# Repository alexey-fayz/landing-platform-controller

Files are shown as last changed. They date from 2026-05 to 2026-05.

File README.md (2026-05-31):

# Active Stabilization Platform Firmware

## Overview

This project implements an embedded firmware for an active stabilization platform that compensates for marine vessel motion (roll and pitch), enabling a quadcopter to land safely on a moving boat or buoy.

The system uses a gimbal-like structure with two BLDC servos, a cascade PID controller, absolute encoder feedback, Hall sensors for commutation, current monitoring, and CAN/UART communication.  
FreeRTOS is used for real-time task management.

---

## Table of Contents

- Features  
- Prerequisites   
- Architecture  
- Communication Interfaces  
- Safety & Monitoring  

---

## Features

- **Two-axis stabilization (roll & pitch)**  
  Keeps the landing platform level despite vessel motion.

- **6-step BLDC commutation**  
  Hall sensors provide rotor position for efficient motor control.

- **Absolute encoder feedback**  
  AS5311 (12-bit, SSI interface) provides precise angular position.

- **Cascade PID control**  
  Inner speed loop + outer position loop for smooth and accurate control.

- **Current limiting & monitoring**  
  INA219 (I²C) provides over-current protection and adaptive power reduction.

- **Real-time operating system (FreeRTOS)**  
  Dedicated tasks for control, communication, telemetry, and diagnostics.

- **CAN bus communication (250 kbit/s)**  
  Receives target angles and transmits telemetry data.

- **UART debug console (115200 baud)**  
  Simple command interface for manual control and debugging.

- **Modular architecture**  
  Clear separation of BSP, control, communication, and utilities.

---

## Prerequisites

### Hardware

- STM32L451CET6 microcontroller  
- BLDC motors with Hall sensors  
- DRV8353 gate driver  
- AS5311 absolute encoder  
- INA219 current sensor  
- CAN transceiver (e.g., ISO1050)  
- 24 V / 5 V / 3.3 V power supplies  

### Software

- STM32CubeMX (project generation)  
- STM32CubeIDE / Keil / IAR / ARM GCC toolchain  
- FreeRTOS (included via CubeMX)  
- UART terminal / CAN analyzer (optional)  

---

## Architecture

The firmware is organized into logical layers:

- **App/** – system initialization, global state, interrupt callbacks
- **BSP/** – low-level hardware drivers (encoder, Hall sensors, DRV8353, INA219)
- **Control/** – PID controllers, filters, estimators, trajectory generation
- **Communication/** – CAN protocol, UART telemetry, command parser

All hardware-specific code is isolated in BSP, ensuring that control logic remains portable and testable.

---

## Communication Interfaces

### UART Console (115200 baud, 8N1)

Connection:
- PA2 → TX  
- PA3 → RX  

#### Commands

| Command | Action |
|---|---|
| `enable` | Enable motor control |
| `disable` | Disable motor control |
| `angle 12.3` | Set target angle (degrees) |
| `status` | Show system state |

---

### CAN Bus (250 kbit/s, standard ID)

#### Receive (ID: 0x100)

Target angle command:

- Data length: 2 bytes  
- Format:
  - `angle (deg) = (byte0 << 8 | byte1) / 10.0`

---

#### Transmit (ID: 0x101)

Telemetry frame (6 bytes):

- `uint16` current angle ×10  
- `int16` current speed ×10  
- `uint8` enable flag  
- `uint8` error flags  

This protocol is compatible with marine-style CAN networks (similar to NMEA2000-like systems).

---

## Safety & Monitoring

### Over-current protection
The INA219 sensor continuously measures motor current.  
If the current exceeds a defined threshold:
- Motor power is reduced gradually, or
- The system is shut down if the condition persists

---

### Fault detection
The DRV8353 gate driver provides an `nFAULT` signal.  
On fault detection:
- PWM outputs are disabled immediately
- System enters safe state

---

### FreeRTOS safety mechanisms
The system uses built-in RTOS safety features:
- Stack overflow detection hooks
- Runtime error callbacks
- Task watchdog logic (if enabled)

---

### Emergency stop behavior
The system can be disabled via:
- UART `disable` command
- CAN stop command

In all cases:
- Motor outputs are immediately disabled
- Control loops are paused
- System transitions to safe idle state

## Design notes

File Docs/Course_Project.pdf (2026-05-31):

Министерство науки и высшего образования Российской Федерации
Федеральное государственное автономное образовательное учреждение
высшего образования
«Московский государственный технический университет имени Н.Э. Баумана
(национальный исследовательский университет)» (МГТУ им. Н.Э. Баумана)

ФАКУЛЬТЕТ СПЕЦИАЛЬНОЕ МАШИНОСТРОЕНИЕ
КАФЕДРА РОБОТОТЕХНИЧЕСКИЕ СИСТЕМЫ И МЕХАТРОНИКА

## РАСЧЕТНО-ПОЯСНИТЕЛЬНАЯ ЗАПИСКА

## К КУРСОВОМУ ПРОЕКТУ НА ТЕМУ:

## Разработка мехатронной системы стабилизации платформы

Студент | СМ7-71Б | Файздрахманов А.И.
(группа) | (подпись, дата) | (И.О. Фамилия)
Руководитель
курсового проекта | Синицын А.В.
(подпись, дата) | (И.О. Фамилия)

2025 г.

Министерство науки и высшего образования Российской Федерации Федеральное государственное автономное образовательное учреждение высшего образования
«Московский государственный технический университет имени Н.Э. Баумана (национальный исследовательский университет)» (МГТУ им. Н.Э. Баумана)
УТВЕРЖДАЮ

Заведующий кафедрой
(индекс)

(И.О. Фамилия)
(подпись)
(дата)
ЗАДАНИЕ
на выполнение курсового проекта

по дисциплине Электронные устройства СРТС ч.2
Студент группы Файздрахманов Алексей Игоревич СМ7-71Б
| (Фамилия, имя, отчество)
Тема курсового проекта Разработка мехатронной системы стабилизации платформы

Направленность КП (учебная, исследовательская, практическая, производственная, др.) учебная

Источник тематики (кафедра,

предприятие, НИР) | кафедра
Задание Проанализировать техническое задание, разработать функциональную и структурную схемы системы управления приводом, разработать плату управления двигателем приводов на оси дифферента и оси крена, спроектировать печатную плату, разработать конструкторскую документацию, состоящую из принципиальной электрической схемы, сборочного чертежа, чертежа печатной платы, спецификации и перечня элементов.

Оформление курсового проекта:
Расчетно-пояснительная записка на 48 листах формата А4.
Перечень графического (иллюстративного) материала (чертежи, плакаты, слайды и т.п.) Схема электрическая принципиальная А3, чертёж печатной платы А3, сборочный чертёж А3, перечень элементов 3 листа А4, спецификация к сборочному чертежу 3 листа А4.

Дата выдачи задания « ___ » ____________ 20__ г.
Руководитель курсового проекта | А.В.Синицын
(подпись, дата) | (И.О. Фамилия)
Студент | А.И.Файздрахманов
(подпись, дата) | (И.О. Фамилия)
Примечание: Задание оформляется в двух экземплярах: один выдается студенту, второй хранится на кафедре.

Министерство науки и высшего образования Российской Федерации Федеральное государственное автономное образовательное учреждение высшего образования
«Московский государственный технический университет имени Н.Э. Баумана (национальный исследовательский университет)» (МГТУ им. Н.Э. Баумана)

КАЛЕНДАРНЫЙ ПЛАН
на выполнение курсового проекта
по дисциплине
Студент группы
(Фамилия, имя, отчество)
Тема курсового
проекта
№ п/п | Наименование этапов выпускной квалификационной работы | Сроки выполнения этапов | Отметка о выполнении
план | факт | Руководитель КП | Куратор
1. Задание на выполнение курсового | проекта
2. | 1 модуль | ____________ Планируемая дата
3. | 2 модуль | ____________ Планируемая дата
4. | Оформление РПЗ | ____________ Планируемая дата
5. Подготовка доклада и презентации | (при необходимости) | ____________ Планируемая дата
6. | Защита курсового проекта | ____________ Планируемая дата
Студент ________________________ | Руководитель проекта _________________________ (подпись, дата) | (подпись, дата)

Оглавление

Введение
Современные робототехнические и мехатронные системы предъявляют всё более высокие требования к качеству, точности и надёжности управления электроприводами. Особенно это касается мобильных и динамически неустойчивых платформ, в составе которых используется сложная система приводов и сенсоров, таких как стабилизирующиеся платформы, манипуляторы, дроны и системы посадки беспилотных летательных аппаратов. В таких комплексах электрический привод является не просто исполнительным механизмом, а элементом, определяющим общую динамику системы, её энергоэффективность и устойчивость при внешних возмущениях.
В последние годы широкое распространение получили бесколлекторные двигатели постоянного тока (BLDC), обладающие высокой удельной мощностью, высоким КПД, малым уровнем шума и отсутствием изнашиваемых коллекторных узлов. Благодаря электронной коммутации обмоток BLDC-двигатели обеспечивают плавное управление моментом и скоростью вращения. Эти преимущества делают их особенно востребованными в малогабаритных робототехнических системах, в том числе и в составе активных выравнивающихся платформ, используемых для автономной посадки дронов на подвижные объекты, например, морские суда или плавучие базы.
В данной курсовом проекте по дисциплине «Электронные устройства» рассматривается проектирование и разработка управляющей платы для бесколлекторного двигателя, предназначенного для работы в составе активной двухосевой стабилизирующей платформы.

Данная плата является частью системы управления, обеспечивающей движение по двум угловым степеням свободы — по крену и по дифференту. Основными функциями платы являются формирование управляющих сигналов для силового драйвера, измерение токов и напряжений в системе, обработка сигналов от датчиков положения ротора, а также обеспечение интерфейса обмена данными с управляющим микроконтроллером.
Таким образом, в ходе выполнения курсового проекта будет спроектировано электронное устройство — управляющая плата для бесколлекторного двигателя, обеспечивающая реализацию базовых функций управления и защиты. В процессе работы будут рассмотрены схемные решения силовой и измерительной части, структура управления, выбор элементной базы, а также особенности компоновки печатной платы. Полученные результаты станут основой для дальнейшей интеграции платы в общую систему управления стабилизирующейся платформой, разрабатываемой в рамках дипломного проекта.

Управление приводами
В данном проекте было решено управлять обоими приводами с помощью двух разных плат управления. Поскольку блок управления будет находиться рядом с управляемым приводом, сигналы будут передаваться на короткие расстояния, что существенно снижает влияние помех, действующих на линии связи.

Структурная схема усилителя следящего привода

Общая структурная схема усилителя мощности следящего привода изображена на Рис. 1. Она управляется драйвером, управляемым микроконтроллером.

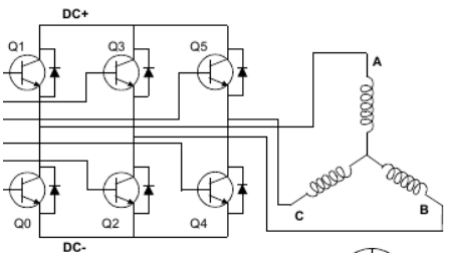
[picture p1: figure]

Рис. 1. Общая схема усилителя мощности следящего привода

Выбор способа управления ДПТ

Существуют два основных способа управления ДПТ: непрерывный и импульсный. При непрерывном способе система обладает сравнительно низким КПД, а транзисторные УМ вносят дополнительную статическую погрешность, поскольку они выполнены по схемам усилителя постоянного тока.

В отличие от непрерывного, импульсный способ управления не обладает этими недостатками и широко используется для управления ДПТ малой и средней мощности. В этом случае ключи работают в режиме класса D и характеризуются меньшими тепловыми потерями. Для данного двигателя будет реализован трапецеидальный способ управления.

Описание трапецеидального способа управления ДПТ

При импульсном управлении по такому способу на ДПТ подается последовательность импульсов одной полярности. Амплитуда соответствует номинальному напряжению якоря UЯН.

# kk = ttuu

TT , | (1)

где k – коэффициент заполнения; tu – длительность импульсов; Т – период следования импульсов.
Коэффициент заполнения пропорционален непрерывному сигналу управления. Если принять Т < TЭ , то скорость двигателя не будет успевать существенно меняться. Значение скорости будет близко к значению, определяемому отношением:
UЯ.СР = k∙UЯН | (2)
Чтобы обеспечить непрерывность тока якоря, а также минимальные потери мощности, следует применить мостовую схему выходного каскада. Такой подход позволяет осуществить режим динамического торможения двигателя между управляющими импульсами. Недостатком мостовой схемы является возможность короткого замыкания.
При этом на фазы двигателя требуется подавать напряжение согласно закону, описанному в таблице 1 и Рис. 2. Здесь sensors – значения с датчиков Холла на роторе двигателя, отражающие его положение.

Таблица 1 – Закон подаваемых сигналов при положительном
| направлении вращения

Электрический угол, ° | Показания датчика Холла | Напряжение на фазах
А | B | C | A | B | C
0-60 | 1 | 0 | 0 | Высокое | - | Низкое
60-120 | 1 | 0 | 1 | Высокое | Низкое | -
120-180 | 0 | 0 | 1 | - | Низкое | Высокое
180-240 | 0 | 1 | 1 | Низкое | - | Высокое
240-300 | 0 | 1 | 0 | Низкое | Высокое | -
300-360 | 1 | 1 | 0 | - | Высокое | Низкое

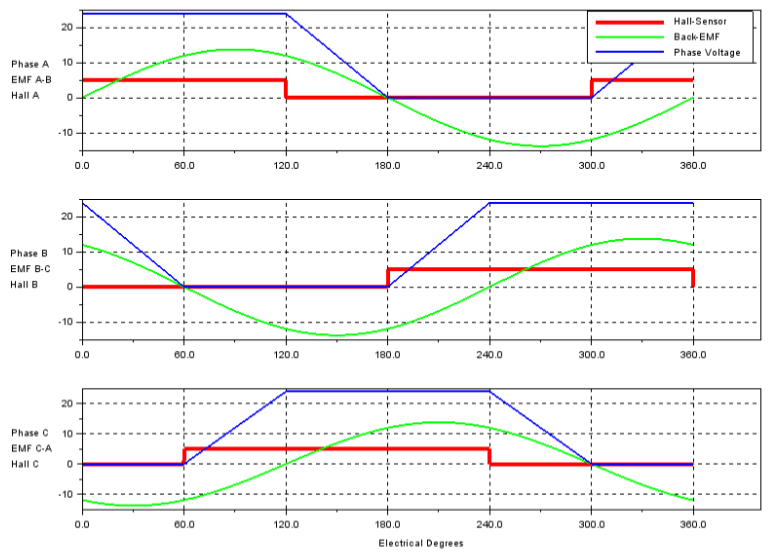
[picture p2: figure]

Рис. 2. Фазные напряжения, показания датчиков и противо-ЭДС на различных обмотках

### 1. Проектирование платы управления на оси

дифферента

### 1.1. Анализ технического задания

В качестве двигателя для данного привода используется трёхфазный бесколлекторный ДПТ с датчиком Холла от компании Fulling Motors FL36RBLS57-24V-4524A. Его характеристики представлены в табл. 2.

Таблица 2 – параметры двигателя FL36RBLS57-24V-4524A
Диаметр | DDд = 36 мм
Мощность | PPд = 24 Вт
Номинальное напряжение | UUд = 24 В
Номинальная скорость | ωωд = 4500 об/мин
Номинальный момент | MMд_ном = 0,05093 Н ∙ м
Сопротивление обмотки | RRд = 2 Ом
Инерция ротора | JJд = 24 ∙ 10⁻⁷ кг ∙ м²
Номинальный ток цепи якоря | IIд = 1,6 А
Пусковой момент | MMд_пуск = 150 Н ∙ мм = 0,15 Н ∙ м
Пусковой ток | IIпуск = 3,8 А

Техническое задание:
Разработать плату управления данным двигателем. Питание платы обеспечить источником питания на 24 В и мощностью 24 Вт.
В ходе конструкторской части работы необходимо:
1) проанализировать техническое задание и подобрать базу необходимых элементов;
2) спроектировать печатную плату в программном пакете Altium Designer;

### 1.2. Разработка структурной схемы

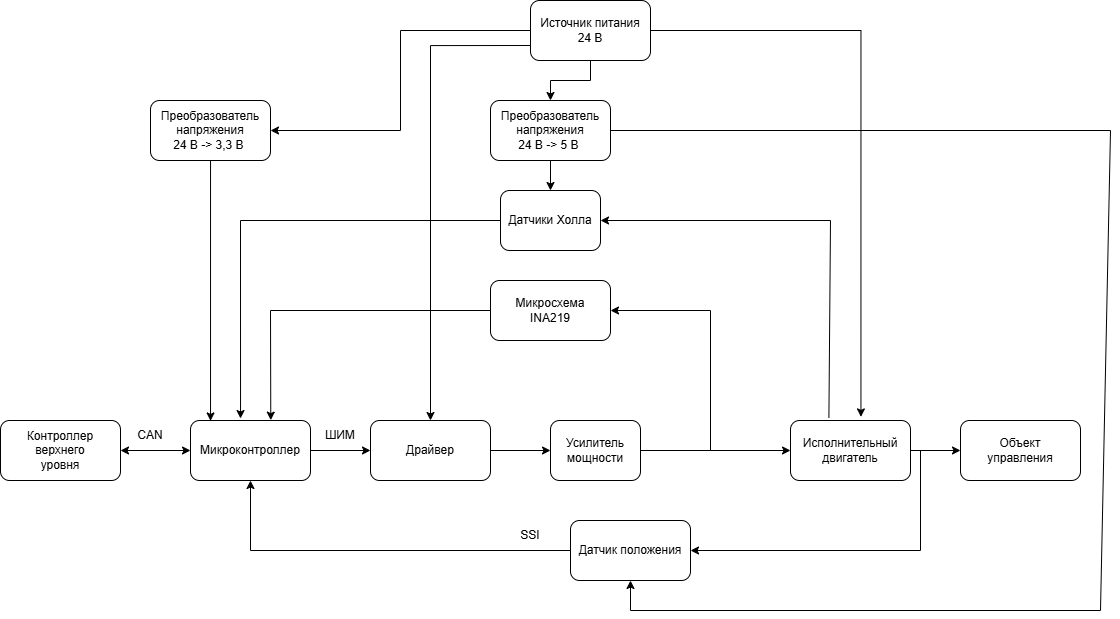
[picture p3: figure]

Рис. 3. Структурная схема системы управления приводом

В данной работе будем выбирать следующие компоненты данной схемы:
- Усилитель мощности (УМ)
- Драйвер

- Датчик положения
- Микроконтроллер
- Преобразователи напряжения

### 1.3. Расчет усилителя мощности

Рассмотрим блок усилителя мощности (рисунок 1). Усилитель мощности будет реализован с использованием мостового каскада. В состав мостового каскада входят полевые транзисторы n-типа с одним источником питания. Все транзисторы были выбраны n-типа для лучшего совпадения их характеристик.
При расчете выходного каскада УМ следует учитывать влияние противо-ЭДС.
1) При разгоне ДПТ в момент времени t=0 : E=0, IЯ = IПУСК. С течением времени IЯ=IНОМ за счет E > 0.
2) При резком изменении направления вращения ротора значение E → UП суммируется с напряжением питания UП, в результате чего в начальный момент времени реверса

# IIЯ = 2IIПУСК (3)

Такое высокое значение тока якоря может вывести из строя ДПТ или транзисторные силовые ключи.
Для того, чтобы исключить влияние выходного каскада УМ как нагрузки, необходимо, чтобы сопротивление ключей моста во включенном состоянии было намного меньше сопротивление якоря двигателя RЯ.

### 1.4. Выбор силовых транзисторных ключей

Выбор силовых транзисторов VT1-VT6 будет проводиться с учетом требований:
1) Напряжение UСИ.MAX = 2*UЯ = 2*24 = 48 В (коэффициент запаса 2)

# 2) IIПУСК = 3,8А, 2 ∗ IIПУСК = 7,6 А

IC.MAX = kЗАПАСА∙ Iогран = 1,2∙7,6 = 9,12 А | (4)

# 3) RRСИ ≤ RRя

20 = 2

| | | 20 = 0.1 Ом | | (5)
4) Частота коммутации должна удовлетворять условия

ff > 10

# TTЭ

= 10

# 0,00072 = 13 889 кГц (6)

для обеспечения непрерывности тока якоря. Примем:

# ff = 15 кГц (7)

В соответствии с этими требованиями выбираем МОП транзистор с
изолированным | затвором | и | каналом | n-типа | фирмы
Youtai Semiconductor IRFR024NTR.
Параметры IRFR024NTR (таблица 3):
Таблица 3 Параметры IRFR024NTR
Параметр | Обозначение | Значение
Максимальное напряжение сток-исток | UСИ.MAX | 55 В
Максимальное напряжение затвор-исток | UЗИ.MAX | 20 В
Максимальный постоянный ток | IС.MAX | 17 А
Сопротивление сток-исток | RСИ | 0,075 Ом
Время нарастания | tн | 34 нс
Время падения | tп | 27 нс
Время задержки включения | tз(вкл) | 4.9 нс
Время задержки выключения | tз(выкл) | 19 нс
tВКЛ=tз(вкл)+tн=4.9 + 34 = 38,9 нс | (8)
tз(вкл) – время задержки при включении, tн – время нарастания
tВЫКЛ=tз(выкл)+tп=19 + 27 = 46 нс | (9)
tз(вкл) – время задержки при выключении, tп – время падения

Временные параметры приведены для UСИ=28 В, UЗИ=10 В, RЗ=24 Ом, IС=10 А.
Напряжение затвор-исток выберем UЗИ = 10 В

Расчет тока управления транзистора

Затвор транзистора представляет собой емкость, которую необходимо зарядить для открытия. Рассчитываем ток управления транзистором:

# IIЗ = QQЗ

# ttнарастания

(10)
Зависимость заряд затвора от напряжений затвор-исток и сток-исток определяется из документации (Рис. 3)

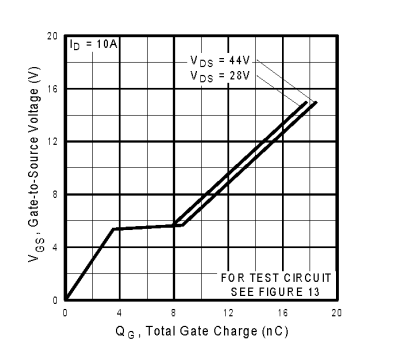
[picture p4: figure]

Рис. 3. График заряда затвора

Uзи = 10 В, Uси = 28 В, тогда QЗ = 13 нКл

# IIЗ = QQЗ

# ttнарастания

# = 13 нКл

# 38.9 нс = 0,334 А (11)

Проверка транзистора по мощности рассеивания

# PP∑ = PPпер + PPнас , (12)

где PPпер - мощность потерь на переключение

# PPпер = UUсиIIС.MMMMMM(ttвкл + ttвыкл)

ff
2 = 28 ∙ 17 ∙ (38.9 + 46) ∙

15 ∙ 10−6
2 =
= 0,303 Вт (13)
PPнас - мощность, потерь в состоянии насыщения

# PPнас = IIсmmmmmm

# 2 RRси = 172 ∙ 0,075 = 21,675 Вт (14) PP∑ = 21,978 Вт < PPС.MMMMMM = 45 Вт (15)

Вывод: полученное значение значительно меньше максимально рассеиваемой мощности транзистора, что позволяет использовать его без дополнительного охлаждения.

Выбор диодов

Выбранный диод должен обеспечить перегрузку по току. Максимально допустимое обратное напряжение диода:

# UUобр.mmmmmm ≥ UUя= 24 В (16)

Время восстановления при резкой смене напряжение с прямого на обратное
tВОС ≤ tВКЛ = 38,9 нс | (17)
В соответствии с этими требованиями выбираем диод Шоттки B230A-13-F с параметрами, казанными в таблице 4.
Таблица 4 – параметры диода Шоттки B230A-13-F
Параметр | Обозначение | Значение
Максимальный ток | IПР.MAX | 50 А
Максимальное обратное напряжение | UОБР.MAX | 30 В
Время восстановления | tВОС | 24 нс

### 1.5. Выбор драйверов

Для управления силовыми ключами мостовых схем необходимы драйверы. Существуют различные типы драйверов в зависимости от объекта управления: драйверы полумостов, драйверы Н-моста, драйверы трехфазного моста.

Основные требования, предъявляемые к нашему драйверу: должен обеспечивать необходимое напряжение 10 В, максимальный ток затвора (не меньше 0.34 А) и временные характеристики для открытия ключей, иметь уровни входных управляющих сигналов, соответствующие низковольтным уровням (3,3 - 5 В), обладать механизмом формирования мертвого времени от короткого замыкания, возможность реализации ограничения по току.
В связи с вышесказанным будем использовать драйвер DRV8328B. Основная схема подключения к трехфазному мосту показана на Рис. 4

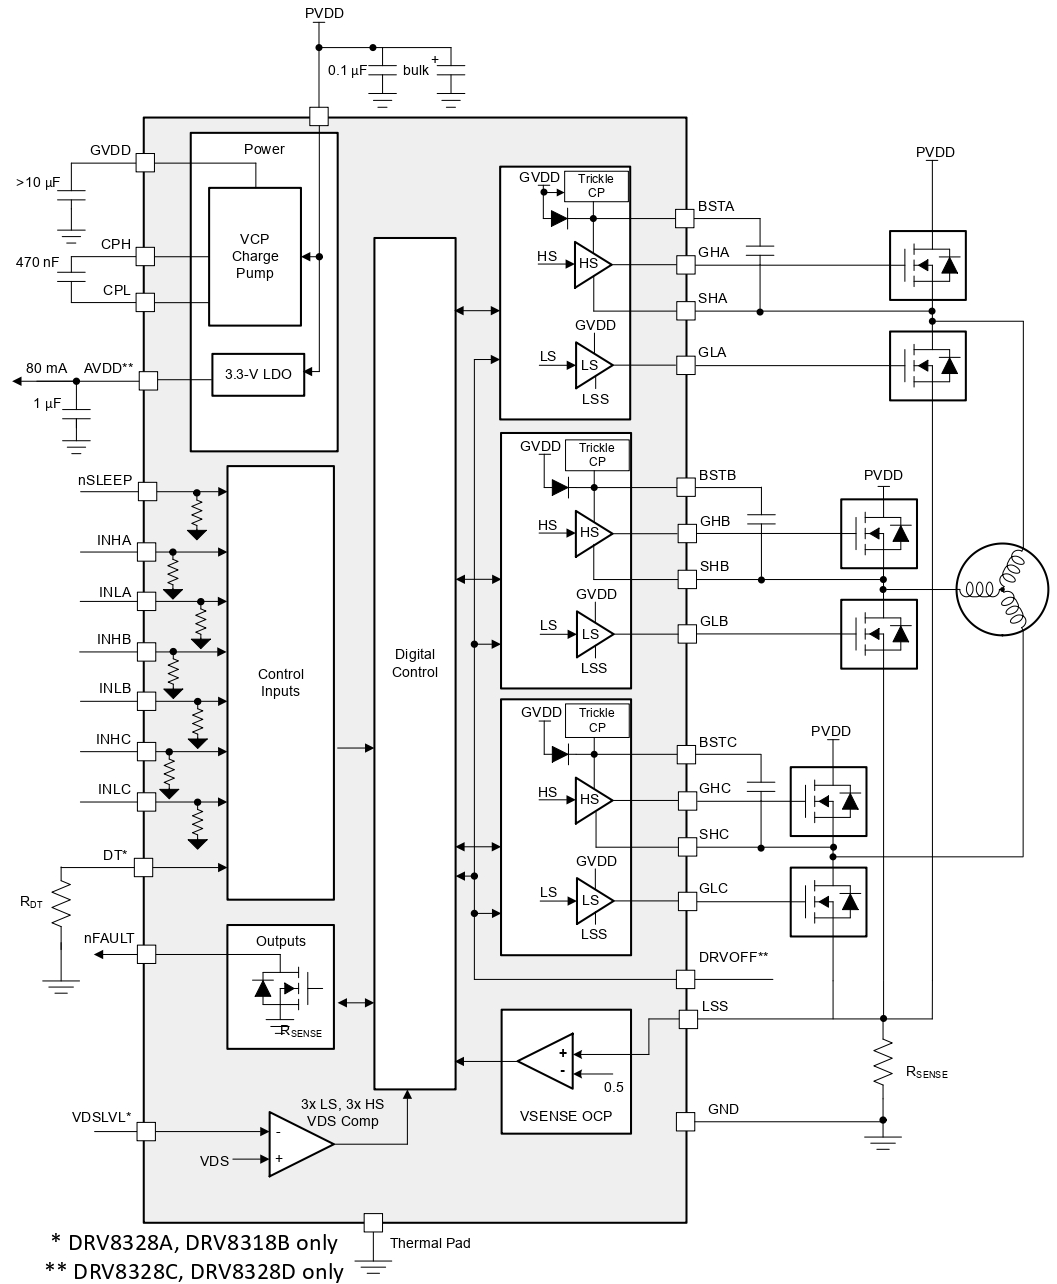
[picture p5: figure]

Рис. 4. Блок диаграмма DRV8328

Таблица 5 - Основные характеристики DRV8328
Параметр | Обозначение | Значение
Напряжение питания | PVDD | 0 … 65 В
Напряжение затвора | Vgvdd | 10…15 В
Максимальный ток включения транзистора | IO+ | 1 А

Максимальный | ток
выключения транзистора
| IO− | 2 А
Задержка нарастания/спада | tr/f | 140 нс
Задержка детектирования управляющего сигнала | ton | 30 нс
сигналов Уровень входных логических | – | 3,3 В и 5 В
Дополнительные функции | Поддержка 3 и 6 канального ШИМ, защита от перегрева, защита от пониженного напряжения, защита от короткого замыкания, настройка мертвого времени, настройка ограничения по току, встроенный бутстрепный диод и зарядный насос, индикатор ошибки

Далее рассчитаем все необходимые элементы обвязки драйвера. Будем опираться на рекомендации производителя и техническую документацию.

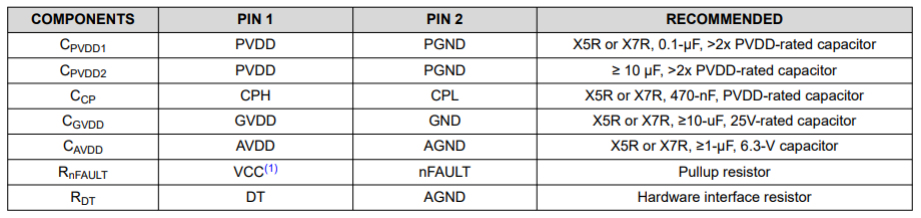
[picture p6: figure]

Рис. 5. Рекомендации параметров внешних компонентов DRV8328

### 1.6. Резисторы затвора. Бутстрепная цепь

Как ранее писалось, в цепи затвора будем использовать рекомендованное сопротивление RR = 24 Ом. Но Texas Instruments предлагает использовать схему с различными путями включения выключения.

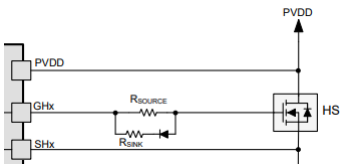
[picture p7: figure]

Рис. 6. Схема с уравниванием времен включения и выключения транзистора

Поскольку частота управляющих ШИМ-сигналов относительно мала по сравнению с максимальной частотой коммутации выбранных силовых ключей (15 кГц и ~5 МГц), то время открытия и закрытия можно принять больше минимальных. Примем ttвкл/выкл = 300 нс. Тогда по графику Рис.7.

можно понять, что среднее сопротивления цепи открытия примерно

# RRssssssssssss = 140 Ом. Мощность рассеивания PP = UUGGGG

2
RR1

= 102

140 = 0,71 Вт.

Выберем резистор на 1 Вт SMD 2512 CRCW2512140RFKEG 140 Ом ±1% Vishay.

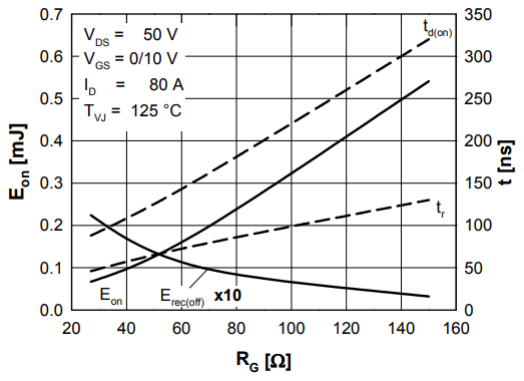
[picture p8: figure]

Рис. 7. График времени открытия от сопротивления затвора

Рассчитаем второй резистор в цепи с диодом.

# Rssss = R ∙ Rssssss

# RRssssssssssss − RR = 24 ∙ 140

140 − 24 = 28,96 Ом (18)

# PP = UUGGGG

2

## RRssssssss

= 102
29 = 3,44 Вт (19)

Будем использовать резистор на 4 Вт SMD 3540 354030RFT 30 Ом ±1% TE Connectivity.

Так как драйвер обладает встроенными бутстрепными диодами, то нам необходимо рассчитать только конденсаторы.
Расчет минимально необходимого заряда бутстрепного кондесатора:

# Qt = 2 ∗ Qg +

# IIbbsstttttttt

## ffШИМ

=
= 22 ∗ 1111 ∗ 1111−99 +

∗ 1111−66
1111 ∗ 1111 = 22 нКл | (20)

Где QQgg - затворный заряд верхнего транзистора, IIbb _tt - ток утечки через бутстрепную цепь драйвера, ffШИМ – частота ШИМ.

Падение напряжения на бутстрепном конденсаторе:

# VV VV = VV VVVVVV − VV VVVV VV − VV VVVV =

= 1111 − 11 − 44. = 44. В (21)

# Где VVVVVVVVVV – напряжение питания завора, VVVVVVVV VV – падение

напряжения на бутстрепном диоде, VVVVVV VVVV – порог блокировки бутстрепа

по пониженному напряжению.
Минимальная емкость бутстрепного конденсатора:

# СБ MM MM = QQБ MM MM

# UUПИТ − UUБД

= 22 ∗ 1111−99
44.
= , 7777 ∗ 1111−99 Ф | (22)

Для обеспечения надежной работы следует выбирать величину бутстрепной емкости из диапазона СБ = 10 ∗ СБ MMMMMM … 15 ∗ СБ MMMMMM:

# СБ = 77, нФ… 66, 77 нФ (23)

Выберем номинал бутстрепного конденсатора 82 нФ. Опираясь на рекомендации документации, используем SMD 0603 C0603C823K5RACTU 82 нФ ±10% Kemet с номинальным напряжением 50В.
Мертвое время
Диапазон значений, из которого можем выбрать, 100…2000 нс. Время регулируется с помощью специального резистора, примем с запасом в 2 раза больше, чем выключение транзистора, 600 нс. Рассчитаем резистор согласно документации:

# RR = DDDD DDDDDDDD( ) − 1111 = 1111 кОм (24)

Берем резистор SMD 2512 CRCW2512110KFKEG 110 кОм ±1% Vishay.

Рис. 8. Резистор мертвого времени

Ограничение по току
Драйвер обладает встроенной возможностью ограничения тока, измеряя падение напряжения на каждом транзисторе и сравнивая с задающим. При обнаружении транзисторы отключаются на 3 мкс, потом идет повторное измерение.

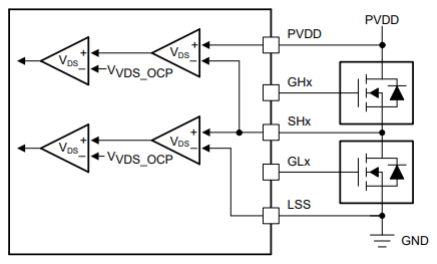
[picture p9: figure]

Рис.10. Блок схема ограничения тока

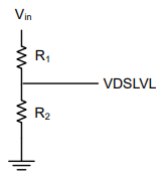
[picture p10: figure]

Рис. 11. Делитель напряжения Опорное напряжение задается с помощью делителя напряжения. Как ранее говорилось, максимальный ток на уровне 9,12 А. Согласно документации:

# VVdd dddddd = II II ∗ RR ( oo) = 9,12 ∗ 0.075 = 0.684 В (25)

RR1

# RR2 = VVVV

# VVVVVVVVVVVV − 1 = 3.3

0.684 − 1 = 3,82 (26)

Выберем резисторы SMD 1206 CRCW12061R00FKTA 1 Ом ±1% Vishay и SMD 1218 CRCW12183R83FKEK 3,83 Ом±1% Vishay. И добавим фильтрующий конденсатор в цепь SMD 0402 GRM155R71C104K 0,1 мкФ ±10% Murata.
Остальная обвязка
Согласно документации, примеру и рекомендуемым значениям установим необходимые конденсаторы вида X5R или X7R с номинальным напряжением минимум, чем в 2 раза выше нормального рабочего напряжения контакта. Для зарядового насоса между контактами CPH и CPL необходим конденсатор SMD 0805 C2012X7R1E474K125AA 0.47 мкФ ±10% TDK. По питанию конденсатор SMD 0402 GRM155R71C104K 0,1 мкФ ±10% Murata и SMD 1206 C3216X7R1H106K160AC 10 мкФ ±10% TDK. На выход питания драйвера затвора между контактами GVDD и GND конденсатор SMD 1812 C4532X7R1H685K250KB 6.8 мкФ ±10% TDK.
Выход nFAULT должен быть подтянут вверх к 3.3 В, используем как в примере резистор SMD 0603 CRG0603F5K11 5.11 кОм ±1% TE Connectivity.

### 1.7. Система управления

Выбор датчика углового положения

Выберем абсолютный магнитный энкодер. Требуется разрядность не менее 10 бит при рабочем угле 360 градусов, чтобы обеспечить точность 0,5 градуса. Поэтому был выбран абсолютный магнитный энкодер AS5311. Его основные параметры:
•Передает данные по интерфейсу SSI.
•Питается от напряжения 5В, либо 3,3В.
•Имеет разрешение 12 бит (4096 отсчетов на оборот).

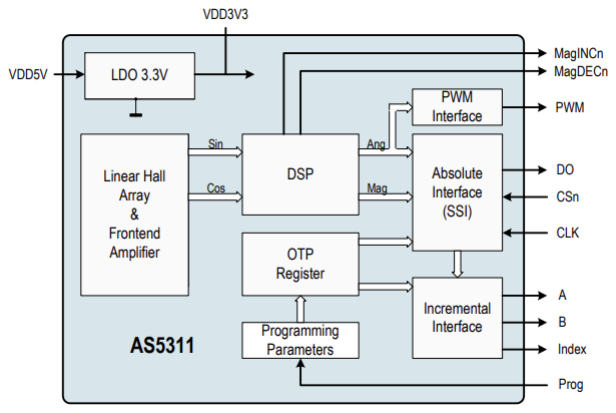
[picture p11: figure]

Рис. 12. Распиновка датчика AS5311

Датчик будет установлен на выходной вал, чтобы избавиться от погрешностей, связанными с зубчатыми передачами.
На рабочих оборотах выходного вала его разрядность обеспечивает требуемую точность:
δδ = 360
212 = 0,088° < 0,5° (27)

Выбор микроконтроллера

Для управления необходимой периферией, обработки информации и реализации различных алгоритмов управления БДПТ необходим производительный микроконтроллер. Исходя из анализа технического задания, можно выдвинуть следующие требования:
- Разрядность – 32 бит
- Возможность генерации сигнала ШИМ по шести каналам
- Три канала таймера для датчиков Холла
- Интерфейс SSI для работы с абсолютным энкодером (датчик положения)
- Достаточное количество пинов для реализации необходимых связей
- Высокая производительность
Нам подходит микроконтроллер STM32L451CET на основе ядра ARM Cortex-M4. Разрядность микроконтроллера 32-разрядная, максимальная частота тактирования 80 МГц, также имеется поддержка вычислений с «плавающей» точкой (FPU), что будет полезно при реализации сложного алгоритма управления. Он обладает всеми необходимыми для работы периферийными модулями.

Подключение датчиков Холла
Используемый двигатель имеет встроенные датчики Холла (напряжение питания 5В). На их выходе мы имеем 3 сигнала, которые можем подключить напрямую к толерантным 5 В ногам МК, которые поддерживают работу с таймером 3 (TIM3).
Согласно документации, присоединять датчики будем разъёмом Molex 43045-0600 6конт.

Подключение абсолютного энкодера
Данный МК поддерживает работу с синхронным интерфейсом. Поэтому сигнал с датчика DO после преобразования мы подключаем к ноге SSI1_MISO, а тактирование CLK будем подавать с ноги SSI1_SCK.

Подключение CAN
На морских суднах зачастую используется протокол NMEA 2000, использующий стандарт передачи CAN. Микроконтроллер поддерживает обмен данными по стандарту CAN. Поэтому мы просто напрямую подключаем ноги CAN1_TX и CAN1_RX к дифференцирующему драйверу преобразователю.
Обвязка
Стабилизированное питание микроконтроллера по документации - 3,3 В. Питание подводится к нескольким выводам в корпусе МК, которые расположены по периметру равномерно, для распределения напряжения по всему кристаллу. Следует поставить блокировочные керамические конденсаторы перед каждым вводом питания и также перед вводом питания аналоговых блоков МК (VDDA/VSSA)
Выбирать номиналы конденсаторов будем согласно технической документации. Используем 3 штуки 0.1мкФ, 1мкФ, 4.7мкФ и 10нФ.

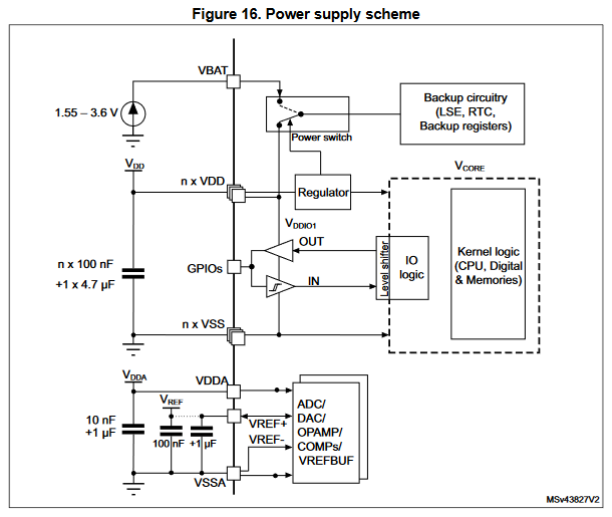
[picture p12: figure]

Рис. 13. Схема обеспечения питания микроконтроллера

Будем использовать внешний кварцевый резонатор (номинальная частота 8МГц), чтобы обеспечить микроконтроллер стабильным сигналом тактирования. Он стабильнее относительно изменения температуры, чем внутренний резонатор МК (который построен на RC-цепочке), и также обладает более высокими характеристиками. Подключать резонатор необходимо через выводы GPIO PH0 и PH1 с дополнительными защитными конденсаторами номиналами 20 пФ согласно документации:

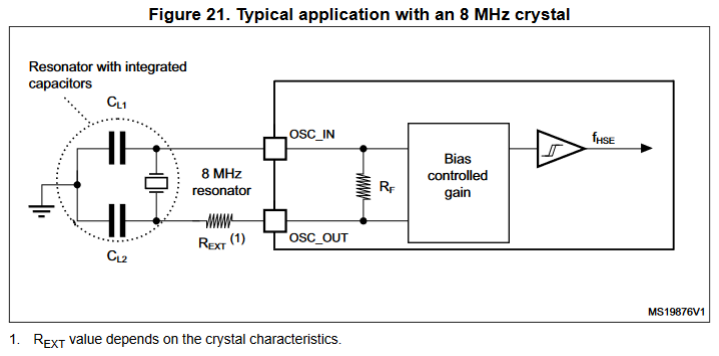
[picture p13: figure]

Рис. 14. Подключение внешнего кварцевого резонатора

Часто в микроконтроллерах предусматривают тактовую кнопку, которая позволяет вручную сбросить микроконтроллер до стартового состояния при отладке или других непредвиденных ситуациях. Кнопка должна стягивать потенциал вывода NRST МК к «земле» при нажатии, параллельно ей подключаем шунтирующий керамический конденсатор 0.1мкФ:

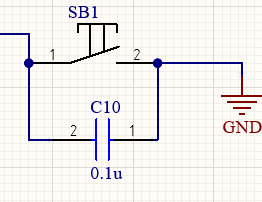
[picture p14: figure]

Рис. 15. Клавиша «Сброс»

Что бы при каждом запуске основная программа загружалась из запоминающего устройства, согласно документации, стянем вывод PH3(BOOT0) МК к «земле» через резистор номиналом 100 кОм. Предусмотрим два дополнительных светодиода, которые могут использоваться для индикации работы, отладки или других требуемых сигналов. Подсоединим их к GPIO PC13 и PC14 микроконтроллера через токоограничивающие резисторы.

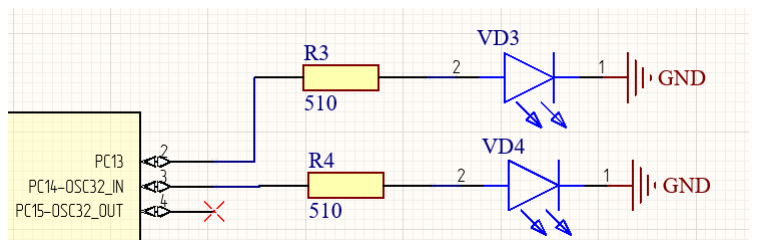
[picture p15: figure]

Рис. 16. Светодиоды-индикаторы

### 1.8. Выбор преобразователя напряжения

Питание платы-драйвера будет осуществляться от источника постоянного напряжения 24 В (батареи), расположенного на палубе судна. Выбор DC-DC преобразователя 24В – 3,3В был выбран DC-DC преобразователь R-783.3–0.5 мощностью 2 Вт фирмы Recom Power. Его характеристики представлены в табл. 6. Описание элементов подключения приведено в табл. 7.
Таблица 6 – характеристики R-783.3-0.5
Выходное напряжение | 3.3 В
Выходной ток | 300мА
Входное напряжение | 6.5-72 В
КПД | 91%

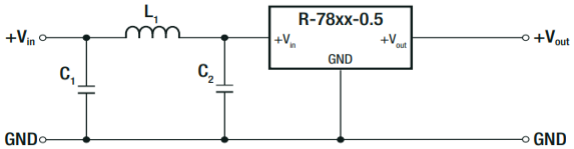
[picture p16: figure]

Рис. 17 – Подключение DC-DC преобразователя

Таблица 7 – элементы подключения DC-DC преобразователя R-783.3-0.5
Элемент Конденсатор 1206 MLCC, 50 В фирмы Kemet | Обозначени CC1 е | Номинал 10 мкФ
Конденсатор 1206 MLCC, 50 В фирмы Kemet | С2 | 3.3 мкФ

Катушка индуктивности RLS-126 Recom Power

LL | 12 мкГн

Выбор DC-DC преобразователя 24В – 5В
В | качестве DC-DC | преобразователя 24В – | 5В выберем
преобразователь напряжения той же фирмы. Характеристики R-785.0–0.5 приведены в табл. 8.

Таблица 8 – характеристики R-785.0-0.5
Выходное напряжение | 5В
Максимальный выходной ток | 500 мА
Входное напряжение | 4.75-32 В
КПД | 91%

Схема подключения данного преобразователя аналогична. Подберем необходимую обвязку (табл. 9).
Таблица 9 – элементы подключения DC-DC преобразователя R-785.0-0.5
Элемент Конденсатор 1206 MLCC, 50 В фирмы Kemet | Обознач CC1, С2 ение | Номинал 2.2 мкФ
Катушка индуктивности RLS-126 Recom Power | LL | 12 кГн

### 1.9. Разработка печатной платы

При разводке печатной платы будем стараться максимально развести силовую и логическую части. В прямом виде в данной плате не присутствует силовая часть, так как управляющие токи небольшие. Но для отсутствия перехода помех от высоковольтной части цепи в низковольтную, будем использовать гальванически развязанные земли для цепей разного напряжения. А также постараемся максимально разнести на плате цепи разного напряжения.
Для уменьшения наводимых шумов реализуем заполнение свободного пространства платы проводником, подключённым к земле различных цепей.

Габариты платы получились равными 90 на 100 мм, что соответствует ГОСТ-у. Все компоненты платы имеют отступ от края платы минимум в 1 мм. Плата изготавливается из двухстороннего стеклотекстолита толщиной в 1,5 мм с проводящим слоем толщиной 0,035 мм. Плата имеет два слоя проводников.
Минимальную ширину дорожек будем определять по следующей формуле:
BB = (

II

# kk ∙ ∆TT0,44)

1
0,725 ∙ 0,0254

(28)
где: II – максимальный ток, протекающий по проводнику; ΔT —

допустимый перепад температуры (°C)(примем 30°C); k — коэффициент, зависящий от толщины меди и расположения слоя (для внешнего слоя и толщины проводящего слоя 0,105мм k=0,144)
Максимальный ток в цепи питания +24 В примем 9,12 А. Тогда:
BB = (

9,12
0,144 ∙ 300,44)

1
0,725 ∙ 0,0254 =
= 0.98 мм
(29)
Примем BB = 11. 22 мм.

Максимальный ток в цепи питания +5 В примем 0,3А. Тогда:
BB = (

0,3
0,144 ∙ 300,44)

1
0,725 ∙ 0,0254 =
= 0,008 мм
(30)
Примем BB = , 22 мм.

Максимальный ток в цепи питания +3,3 В примем 0,3А. Тогда:
BB = (

0,3
0,144 ∙ 300,44)

1
0,725 ∙ 0,0254 = 0,008 мм

(31)
Примем BB = , 22 мм.

Закрепление платы осуществляется 4-мя винтами размером М5, для того предусмотрены крепёжные отверстия по краям платы. Расстояние между элементами платы зададим не менее 0,2 мм, что соответствует 4 классу точности печатных плат. Для избегания наведения помех при разводке платы будем стремиться к увеличению расстояния между компонентами и дорожками до 1 мм, где это представляется возможным.
Разводка платы осуществлена при помощи программного пакета Altium Designer v25.9.1.

### 2. Проектирование платы управления на оси крена

### 2.1. Анализ технического задания

В качестве двигателя для данного привода используется трёхфазный бесколлекторный ДПТ с датчиком Холла от компании Fulling Motors FL42BLA04. Его характеристики представлены в табл. 10.
Таблица 10 – параметры двигателя FL42BLA04
Диаметр | DDд = 42 мм
Мощность | PPд = 113 Вт
Номинальное напряжение | UUд = 24 В
Номинальная скорость | ωωд = 3000 об/мин
Номинальный момент | MMд_ном = 0,3597 Н ∙ м
Сопротивление обмотки | RRд = 0,5 Ом
Инерция ротора | JJд = 207 ∙ 10⁻⁷ кг ∙ м²
Номинальный ток цепи якоря | IIд = 5,8 А
Пусковой момент | MMд_пуск = 1320 Н ∙ мм = 1,32 Н ∙ м
Пусковой ток | IIпуск = 21 А

Техническое задание:
Разработать плату управления данным двигателем. Питание платы обеспечить источником питания на 24 В и мощностью 113 Вт.
В ходе конструкторской части работы необходимо:
1) Проанализировать техническое задание и подобрать базу необходимых элементов;
2) Спроектировать печатную плату в программном пакете Altium Designer;

### 2.2. Разработка структурной схемы

Рис. 18. Структурная схема системы управления приводом

В данной работе будем выбирать следующие компоненты данной схемы:
- Усилитель мощности (УМ)
- Драйвер
- Датчик положения

- Микроконтроллер
- Преобразователи напряжения

### 2.3. Расчет усилителя мощности

Рассмотрим блок усилителя мощности (рисунок 1). Усилитель мощности будет реализован с использованием мостового каскада. В состав мостового каскада входят полевые транзисторы n-типа с одним источником питания. Все транзисторы были выбраны n-типа для лучшего совпадения их характеристик.
При расчете выходного каскада УМ следует учитывать влияние противо-ЭДС.
1) При разгоне ДПТ в момент времени t=0 : E=0, IЯ = IПУСК.
С течением времени IЯ=IНОМ за счет E > 0.
2) При резком изменении направления вращения ротора значение E → UП суммируется с напряжением питания UП, в результате чего в начальный момент времени реверса

# IIЯ = 2IIПУСК (32)

Такое высокое значение тока якоря может вывести из строя ДПТ или транзисторные силовые ключи.
Для того, чтобы исключить влияние выходного каскада УМ как нагрузки, необходимо, чтобы сопротивление ключей моста во включенном состоянии было намного меньше сопротивление якоря двигателя RЯ.

### 2.4. Выбор силовых транзисторных ключей

Выбор силовых транзисторов VT1-VT6 будет проводиться с учетом требований:
1) Напряжение UСИ.MAX = 2*UЯ = 2*24 = 48 В (коэффициент запаса 2)

# 2) IIПУСК = 17,5 А, 2 ∗ IIПУСК = 35 А

IC.MAX = kЗАПАСА∙ Iогран = 1,2∙35 = 42 А | (33)

# 3) RRСИ ≤ RRя

20 = 0,5

20 = 0.025 Ом (34)

4) Частота коммутации должна удовлетворять условия

ff > 10

# TTЭ

= 10

# 0,0029 = 3,45 кГц (35)

для обеспечения непрерывности тока якоря. Примем:

# ff = 3,5 кГц (36)

В соответствии с этими требованиями выбираем МОП транзистор с изолированным затвором и каналом n-типа фирмы Youtai Semiconductor IRFR3806TR.
Параметры IRFR3806TR (таблица 11):
Таблица 11 Параметры IRFR3806TR:
Параметр | Обозначение | Значение
Максимальное напряжение сток-исток | UСИ.MAX | 60 В
Максимальное напряжение затвор-исток | UЗИ.MAX | 20 В
Максимальный постоянный ток | IС.MAX | 43 А
Сопротивление сток-исток | RСИ | 0,016 Ом
Время нарастания | tн | 40 нс
Время падения | tп | 47 нс
Время задержки включения | tз(вкл) | 6.3 нс
Время задержки выключения | tз(выкл) | 49 нс
tВКЛ=tз(вкл)+tн=6,3 + 40 =4 6,3 нс | (37)
tз(вкл) – время задержки при включении, tн – время нарастания
tВЫКЛ=tз(выкл)+tп=49 + 47 = 86 нс | (38)
tз(вкл) – время задержки при выключении, tп – время падения

Временные параметры приведены для UСИ=30 В, UЗИ=10 В, RЗ=20 Ом, IС=25 А.
Напряжение затвор-исток выберем UЗИ = 10 В.

Расчет тока управления транзистора

Затвор транзистора представляет собой емкость, которую необходимо зарядить для открытия. Рассчитываем ток управления транзистором:

# IIЗ = QQЗ

# ttнарастания

(39)
Зависимость заряд затвора от напряжений затвор-исток и сток-исток определяется из документации (Рис. 19)

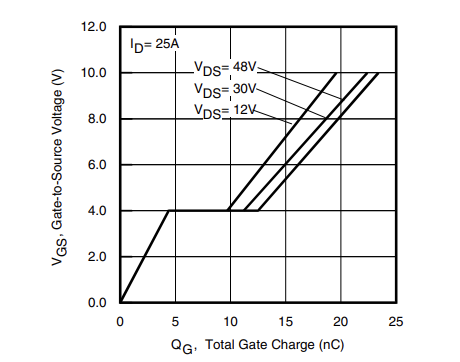
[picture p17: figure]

Рис. 19. График заряда затвора

Uзи = 10 В, Uси = 30 В, тогда QЗ = 22 нКл

# IIЗ = QQЗ

# ttнарастания

# = 22 нКл

# 46,3 нс = 0,48 А (40)

Проверка транзистора по мощности рассеивания

# PP∑ = PPпер + PPнас , (41)

где PPпер - мощность потерь на переключение

# PPпер = UUсиIIС.MMMMMM(ttвкл + ttвыкл)

ff
2 = 30 ∙ 43 ∙ (46,3 + 86) ∙

3,5 ∙ 10−6
2 =
= 0,3 Вт (42)
PPнас - мощность, потерь в состоянии насыщения

# PPнас = IIсmmmmmm

# 2 RRси = 432 ∙ 0,016 = 29,6 Вт (43) PP∑ = 29,9 Вт < PPС.MMMMMM = 71 Вт (44)

Вывод: полученное значение значительно меньше максимально рассеиваемой мощности транзистора, что позволяет использовать его без дополнительного охлаждения.

Выбор диодов

Выбранный диод должен обеспечить перегрузку по току. Максимально допустимое обратное напряжение диода:

# UUобр.mmmmmm ≥ UUя= 24 В (45)

Время восстановления при резкой смене напряжение с прямого на обратное
tВОС ≤ tВКЛ = 46,3 нс | (46)
В соответствии с этими требованиями выбираем диод Шоттки B230A-13-F с параметрами, казанными в таблице 8.
Таблица 12 – параметры диода Шоттки G3S17050PM
Параметр | Обозначение | Значение
Максимальный ток | IПР.MAX | 50 А
Максимальное обратное напряжение | UОБР.MAX | 30 В
Время восстановления | tВОС | 24 нс

### 2.5. Выбор драйверов

Для управления силовыми ключами мостовых схем необходимы драйверы. Существуют различные типы драйверов в зависимости от объекта управления: драйверы полумостов, драйверы Н-моста, драйверы трехфазного моста.

Основные требования, предъявляемые к нашему драйверу: должен обеспечивать необходимое напряжение 10 В, максимальный ток затвора (не меньше 0.48 А) и временные характеристики для открытия ключей, иметь уровни входных управляющих сигналов, соответствующие низковольтным уровням (3,3 - 5 В), обладать механизмом формирования мертвого времени от короткого замыкания, возможность реализации ограничения по току.
В связи с вышесказанным будем использовать драйвер DRV8328B. Основная схема подключения к трехфазному мосту показана на Рис. 20.

Рис. 20. Блок диаграмма DRV8328

Таблица 13 - Основные характеристики DRV8328
Параметр | Обозначение | Значение
Напряжение питания | PVDD | 0 … 65 В
Напряжение затвора | Vgvdd | 10…15 В
Максимальный ток включения транзистора | IO+ | 1 А

Максимальный | ток
выключения транзистора
| IO− | 2 А
Задержка нарастания/спада | tr/f | 140 нс
Задержка детектирования управляющего сигнала | ton | 30 нс
сигналов Уровень входных логических | – | 3,3 В и 5 В
Дополнительные функции | Поддержка 3 и 6 канального ШИМ, защита от перегрева, защита от пониженного напряжения, защита от короткого замыкания, настройка мертвого времени, настройка ограничения по току, встроенный бутстрепный диод и зарядный насос, индикатор ошибки

Далее рассчитаем все необходимые элементы обвязки драйвера. Будем опираться на рекомендации производителя и техническую документацию.

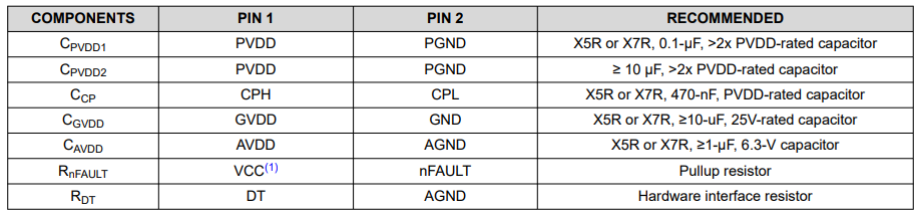
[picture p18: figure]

Рис. 21. Рекомендации параметров внешних компонентов DRV8328

### 2.6. Резисторы затвора. Бутстрепная цепь

Как ранее писалось, в цепи затвора будем использовать рекомендованное сопротивление RR = 20 Ом. Но Texas Instruments предлагает использовать схему с различными путями включения выключения.

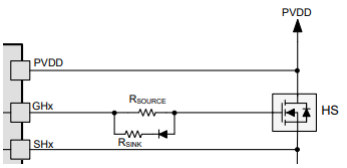
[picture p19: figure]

Рис. 22. Схема с уравниванием времен включения и выключения транзистора

Поскольку частота управляющих ШИМ-сигналов относительно мала по сравнению с максимальной частотой коммутации выбранных силовых ключей (3,5 кГц и ~5 МГц), то время открытия и закрытия можно принять больше минимальных. Примем ttвкл/выкл = 300 нс. Тогда по графику Рис.

23. можно понять, что среднее сопротивления цепи открытия примерно

# RRssssssssssss = 140 Ом. Мощность рассеивания PP = UUGGGG

2
RR1

= 102

140 = 0,71 Вт.

Выберем резистор на 1 Вт SMD 2512 CRCW2512140RFKEG 140 Ом ±1% Vishay

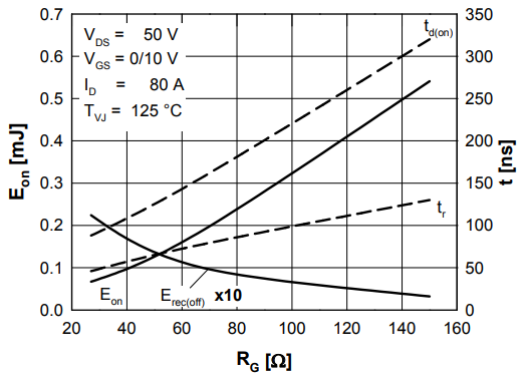
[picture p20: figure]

Рис. 23. График времени открытия от сопротивления затвора

Рассчитаем второй резистор в цепи с диодом.

# Rssss = R ∙ Rssssss

# RRssssssssssss − RR = 20 ∙ 140

140 − 20 = 23,3 Ом (47)

# PP = UUGGGG

2

## RRssssssss

= 102
24 = 4,17 Вт (48)

Будем использовать резистор на 5 Вт AC05000002409JAC00 24 Ом ±5%
Vishay.

Так как драйвер обладает встроенными бутстрепными диодами, то нам необходимо рассчитать только конденсаторы.
Расчет минимально необходимого заряда бутстрепного кондесатора:

# Qt = 2 ∗ Qg +

# IIbbsstttttttt

## ffШИМ

= 22 ∗ 2222 ∗ 1111−99 +

∗ 1111−66
. ∗ 1111 = 111111 нКл | (49)

Где QQgg - затворный заряд верхнего транзистора, IIbb _tt - ток утечки через бутстрепную цепь драйвера, ffШИМ – частота ШИМ.

Падение напряжения на бутстрепном конденсаторе:

# VV VV = VV VVVVVV − VV VVVV VV − VV VVVV

= 1111 − 11 − 44. = 44. В (50)

# Где VVVVVVVVVV – напряжение питания завора, VVVVVVVV VV – падение

напряжения на бутстрепном диоде, VVVVVV VVVV – порог блокировки бутстрепа

по пониженному напряжению.
Минимальная емкость бутстрепного конденсатора:

# СБ MM MM = QQБ MM MM

# UUПИТ − UUБД

= 11 ∗ 1111−99
44. =
= 22 , 99 ∗ 1111−99 Ф | (51)

Для обеспечения надежной работы следует выбирать величину бутстрепной емкости из диапазона СБ = 10 ∗ СБ MMMMMM … 15 ∗ СБ MMMMMM:

# СБ = 22 нФ… 44 , нФ (52)

Выберем номинал бутстрепного конденсатора 390 нФ. Опираясь на рекомендации документации, используем SMD 0805 0805B394K500CT 390 нФ ±10% Walsin с номинальным напряжением 50В.
Мертвое время
Диапазон значений, из которого можем выбрать, 100…2000 нс. Время регулируется с помощью специального резистора, примем с запасом в 2 раза больше, чем выключение транзистора, 600 нс. Рассчитаем резистор согласно документации:

# RR = DDDD DDDDDDDD( ) − 1111 = 1111 кОм (53)

Берем резистор SMD 2512 CRCW2512110KFKEG 110 кОм ±1% Vishay.

Рис. 24. Резистор мертвого времени

Ограничение по току
Драйвер обладает встроенной возможностью ограничения тока, измеряя падение напряжения на каждом транзисторе и сравнивая с задающим. При обнаружении транзисторы отключаются на 3 мкс, потом идет повторное измерение.

Рис. 25. Блок схема ограничения тока

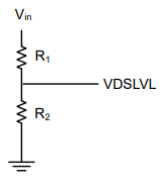
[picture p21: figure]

Рис. 26. Делитель напряжения Опорное напряжение задается с помощью делителя напряжения. Как ранее говорилось, максимальный ток на уровне 42 А. Согласно документации:

# VVdd dddddd = II II ∗ RR ( oo) = 42 ∗ 0.016 = 0.672 В (54)

RR1

# RR2 = VVVV

# VVVVVVVVVVVV − 1 = 3.3

0.672 − 1 = 3,9 (55)

Выберем резисторы SMD 1206 CRCW12061R00FKTA 1 Ом ±1% Vishay и SMD 1225 RCL12253R90JNEG 3,9±1% Vishay. И добавим фильтрующий конденсатор в цепь SMD 0402 GRM155R71C104K 0,1 мкФ ±10% Murata.

Остальная обвязка
Согласно документации, примеру и рекомендуемым значениям установим необходимые конденсаторы вида X5R или X7R с номинальным напряжением минимум чем в 2 раза выше нормального рабочего напряжения контакта. Для зарядового насоса между контактами CPH и CPL необходим конденсатор SMD 0805 C2012X7R1E474K125AA 0.47 мкФ ±10% TDK. По питанию конденсатор SMD 0402 GRM155R71C104K 0,1 мкФ ±10% Murata и SMD 1206 C3216X7R1H106K160AC 10 мкФ ±10% TDK. На выход питания драйвера затвора между контактами GVDD и GND конденсатор SMD 1812 C4532X7R1H685K250KB 6.8 мкФ ±10% TDK.
Выход nFAULT должен быть подтянут вверх к 3.3 В, используем как в примере резистор SMD 0603 CRG0603F5K11 5.11 кОм ±1% TE Connectivity.

### 2.7. Система управления

Выбор датчика положения и микроконтроллера полностью аналогичен первому приводу.

### 2.8. Выбор преобразователя напряжения

Выбор преобразователей напряжения полностью аналогичен первому приводу.

### 2.9. Разработка печатной платы

Разработка печатной платы полностью аналогична первому приводу.

Заключение

В ходе выполнения курсового проекта была разработана печатная плата управления бесколлекторным двигателем, предназначенная для использования в составе мехатронной системы стабилизации платформы. Учтены требования, представленные в техническом задании, а также специфика самого двигателя — бесколлекторный двигатель с необходимостью точного регулирования положения выходного звена. Был проведён расчет усилителя мощности, а также выбор силовых транзисторных ключей, драйверов, микроконтроллеров, преобразователей напряжения и элементов обвязки. На основании сравнения различных типов драйверов и микроконтроллеров выбрана архитектура системы на основе специализированного контроллера управления двигателем с поддержкой ШИМ-модуляции и измерения данных с датчиков Холла. Разработаны структурная и принципиальная схемы электронного блока, определена номенклатура элементов силовой и управляющей частей, включая выбор МОП-транзисторов, драйверов затворов, компонентов измерения тока и схем защиты.
Выполнен проект печатной платы с соблюдением требований к силовой электронике: обеспечение допустимого теплового рассеивания элементов, разделение силовых и сигнальных линий, оптимальное размещение элементов развязки питания для снижения помех. Разработанное электронное устройство способно обеспечивать работу привода в режиме точного позиционирования, что напрямую влияет на безопасность и автономность посадки квадрокоптера на подвижную платформу.
Таким образом, цели курсового проекта достигнуты: создана полнофункциональная управляющая плата для бесколлекторного двигателя, удовлетворяющая техническим требованиям и подходящая для интеграции в состав мехатронной системы.

Список использованных источников

1. Техническая документация на транзистор IRFR024NTR. URL: https://static.chipdip.ru/lib/626/DOC025626218.pdf
2. Техническая | документация | на | диод | Шоттки
G3S17050PM. URL: https://macrogroup.ru/upload/iblock/ee5/nm5pj10pli6m8yvfbxmflps82i2zbdy6/G3S17050PM.pdf
3. Техническая документация на драйвер DRV8328. URL: https://www.ti.com/lit/ds/symlink/drv8328.pdf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 ww.alldatasheet.com%252F
4. Техническая документация на датчик положения AS5311. URL: https://static.chipdip.ru/lib/618/DOC011618458.pdf
5. Техническая | документация | на | микроконтоллер
STM32L451CET. URL: https://static.chipdip.ru/lib/007/DOC02 5007670.pdf
6. Техническая документация на преобразователь напряжения NDL2405SC. URL: https://static.chipdip.ru/lib/846/DOC016846 326.pdf
7. Техническая | документация | на | преобразователь
напряжения TRN12410. URL: https://static.chipdip.ru/lib/348/DOC011348600.pdf
8. Техническая документация на транзистор IRFR3806TR. URL: https://static.chipdip.ru/lib/207/DOC035207082.pdf
9. Красовский А. Б. Основы электропривода : учебное пособие. — 2-е изд., испр. — Москва : Изд-во МГТУ им. Н. Э. Баумана, 2019. — 407 с. Сурков, А. А. Электромеханические системы автоматического управления : учебное пособие / А.

А. Сурков. — Москва : Изд-во МГТУ им. Н. Э. Баумана, 2016. — 255 с. — ISBN 978-5-7038-4525-7.
10. Дмитриев, М. Н. Электроприводы мехатронных систем : учебник / М. Н. Дмитриев, В. Г. Малышев, А. В. Храмшин. — Москва : Изд-во МГТУ им. Н. Э. Баумана, 2021. — 420 с. — ISBN 978-5-7038-5710-6.
11. Анучин А. С. Системы управления электроприводов: учебник для вузов. – М.: Издательский дом МЭИ, 2015.–373 С.
12. Следящие приводы: В 3 т. 2-е изд., перераб. и доп. / Под ред. Б. К. Чемоданова. Т. 2: Электрические следующие приводы / Е.С. Блейз, В.Н. Бродовский, В. А. Введенский и др. – М.: Изд-во МГТУ им. Н. Э. Баумана, 2003.–880 с.

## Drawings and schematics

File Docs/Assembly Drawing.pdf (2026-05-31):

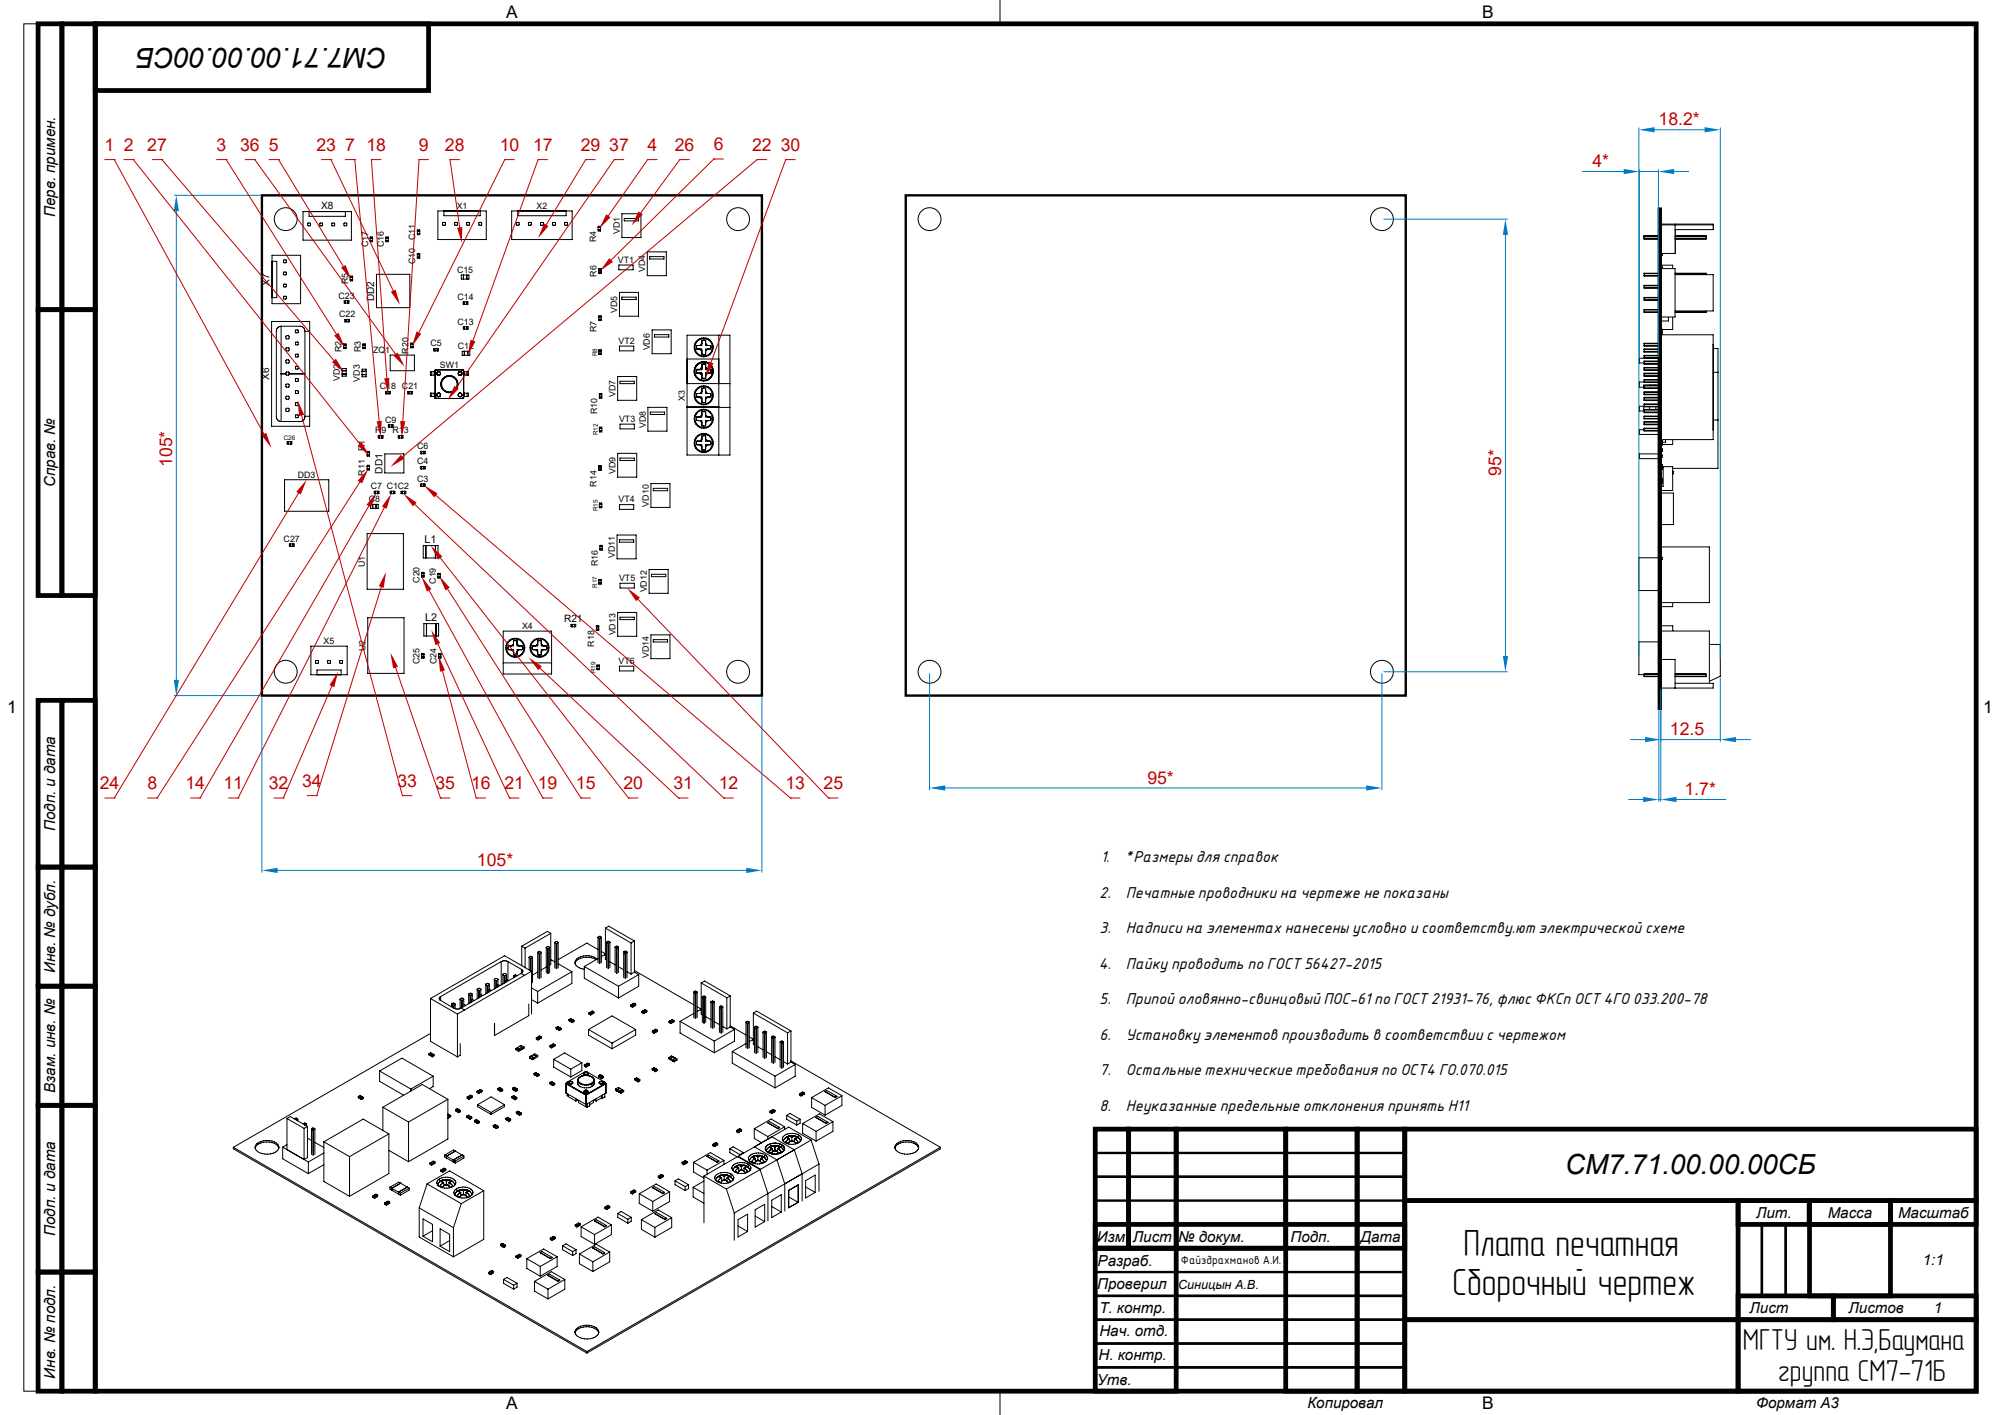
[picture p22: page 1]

Перв. примен. Справ. № Подп. и дата Инв. № дубл. Взам. инв. № Подп. и дата Инв. № подл.

2. Печатные проводники на чертеже не показаны

3. Надписи на элементах нанесены условно и соответству.ют электрической схеме

4. Пайку проводить по ГОСТ 56427-2015

5. Припой оловянно-свинцовый ПОС-61 по ГОСТ 21931-76, флюс ФКСп ОСТ 4ГО 033.200-78

6. Установку элементов производить в соответствии с чертежом

7. Остальные технические требования по ОСТ4 ГО.070.015

8. Неуказанные предельные отклонения принять H11

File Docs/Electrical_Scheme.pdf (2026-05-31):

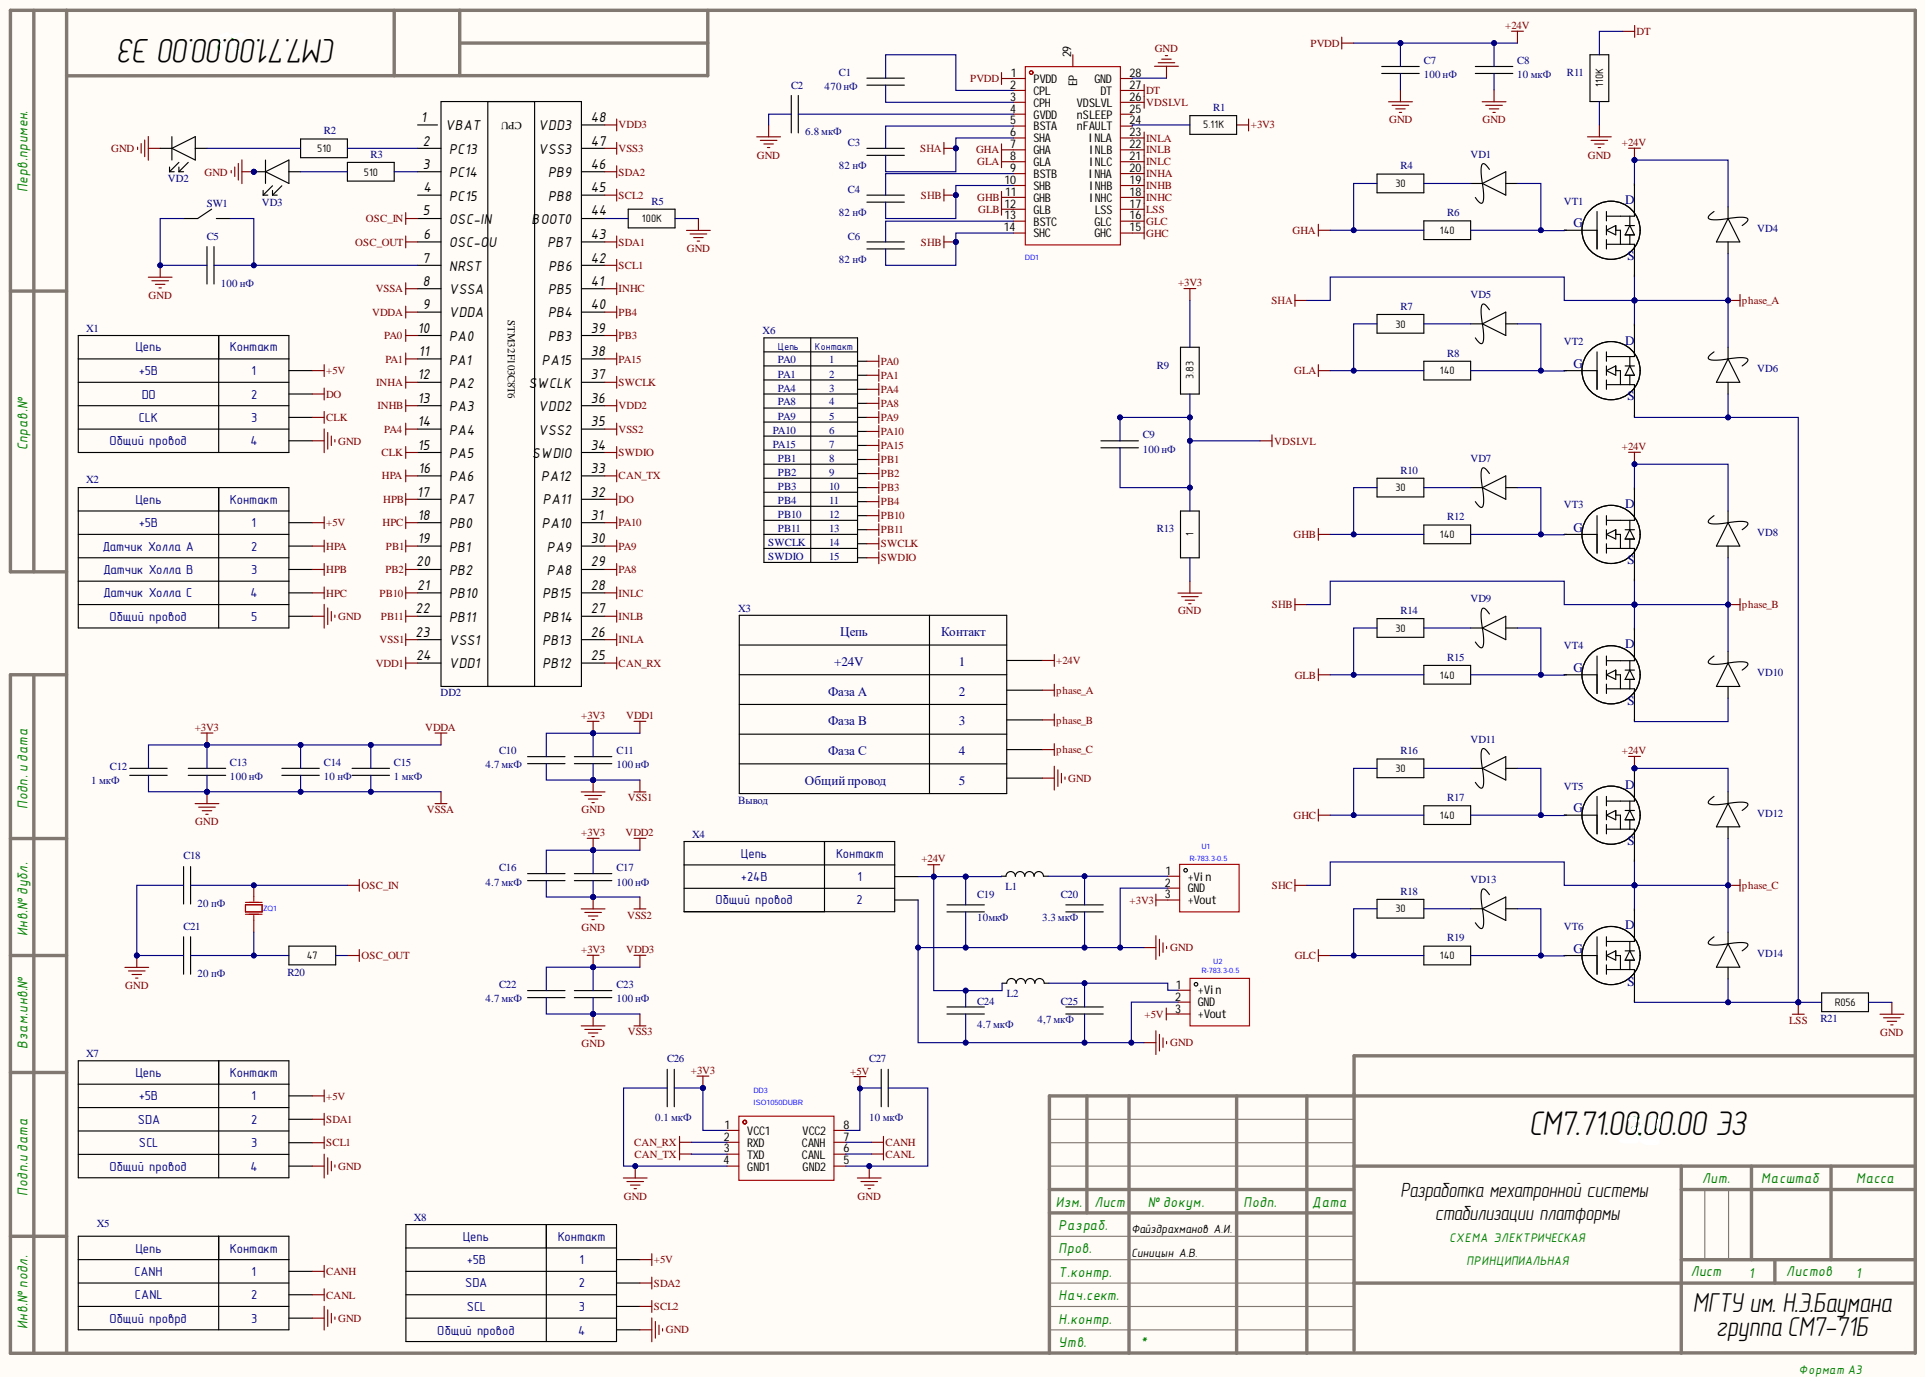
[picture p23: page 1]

2 | 27
3 | 26

1 | 1 | | 1 8
G | 1 2 | | 1 7
1 3 | | 1 6

Общий провод | 4

PA 1 0 | 6
PA 1 5 | 7

P B 1 | 8
P B 2 | 9
P B 3 | 1 0

SWD IO | 1 5

Датчик Холла В | 3

Датчик Холла С | 4

Общий провод | 5

Фаза А | нтакт 12345

Цеп ь | Ко

Инв.№ подл. Подп.и дата Взам.инв.№ Инв.№ дубл. Подп. и дата

Фаза В

Фаза С

Разработка мехатронной системы стабилизации платформы С Х Е М А Э Л Е К ТРИЧЕ СКА Я П Р И Н ЦИПИАЛЬНА Я | Л и т . | М а с ш т а б | М а с с а

Цепь | Контакт

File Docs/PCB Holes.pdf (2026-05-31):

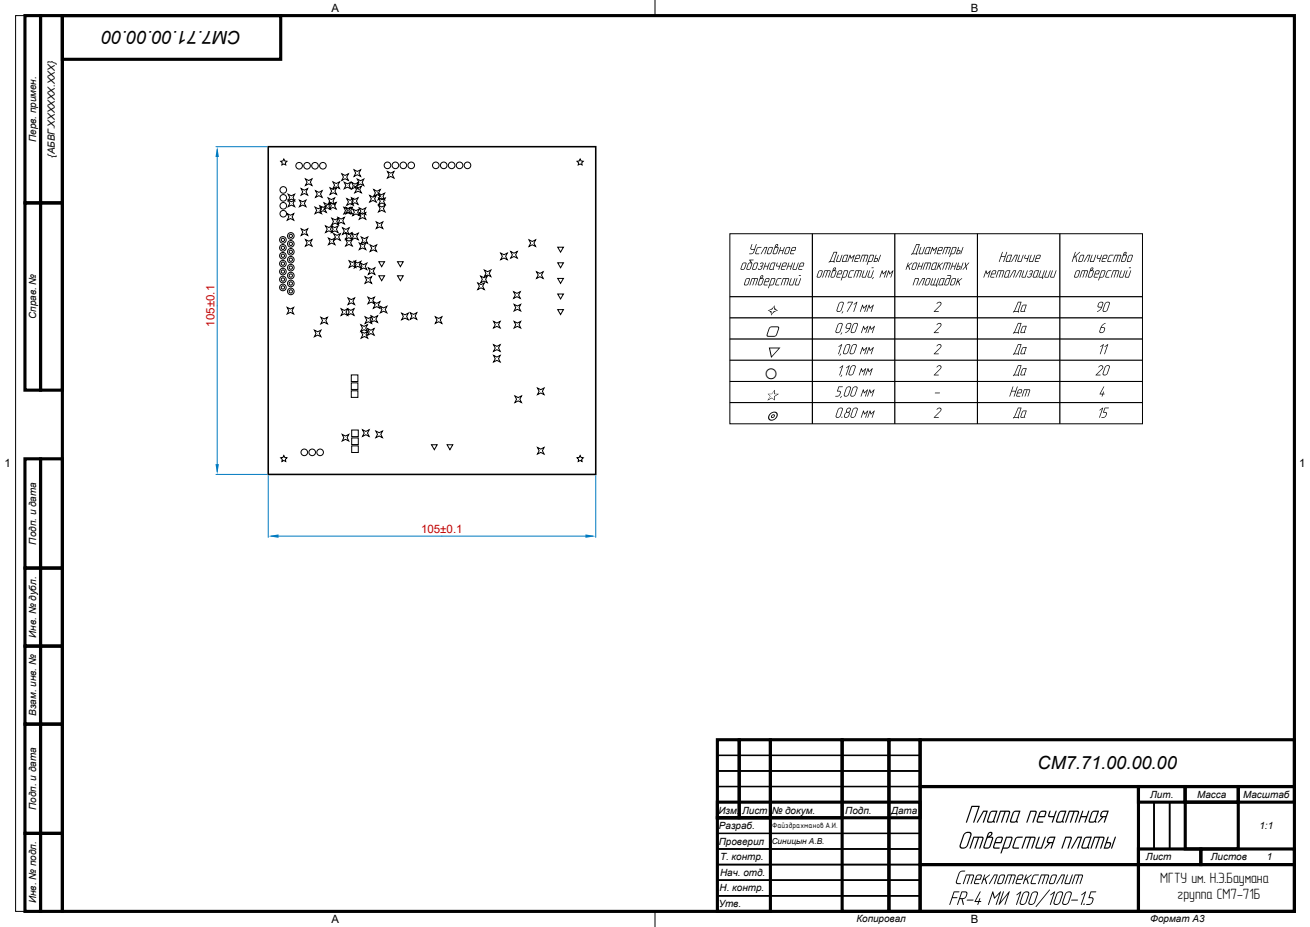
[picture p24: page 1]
Изм. Лист № докум. Разраб.; Подп.; Дата; Проверил Т. контр.; Н. контр. Утв.; Лит.; Масса; Масштаб; Лист; Листов; Синицын А.В.; Копировал; Формат А3; Нач. отд.; Файздрахманов А.И.; New Text ○

{АБВГ.ХХХХХХ.ХХХ}

Перв. примен. Справ. № Подп. и дата Инв. № дубл. Взам. инв. № Подп. и дата Инв. № подл.

МГТУ им. Н.Э.Баумана
группа СМ7-71Б

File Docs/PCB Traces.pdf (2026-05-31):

Ra1,25( )

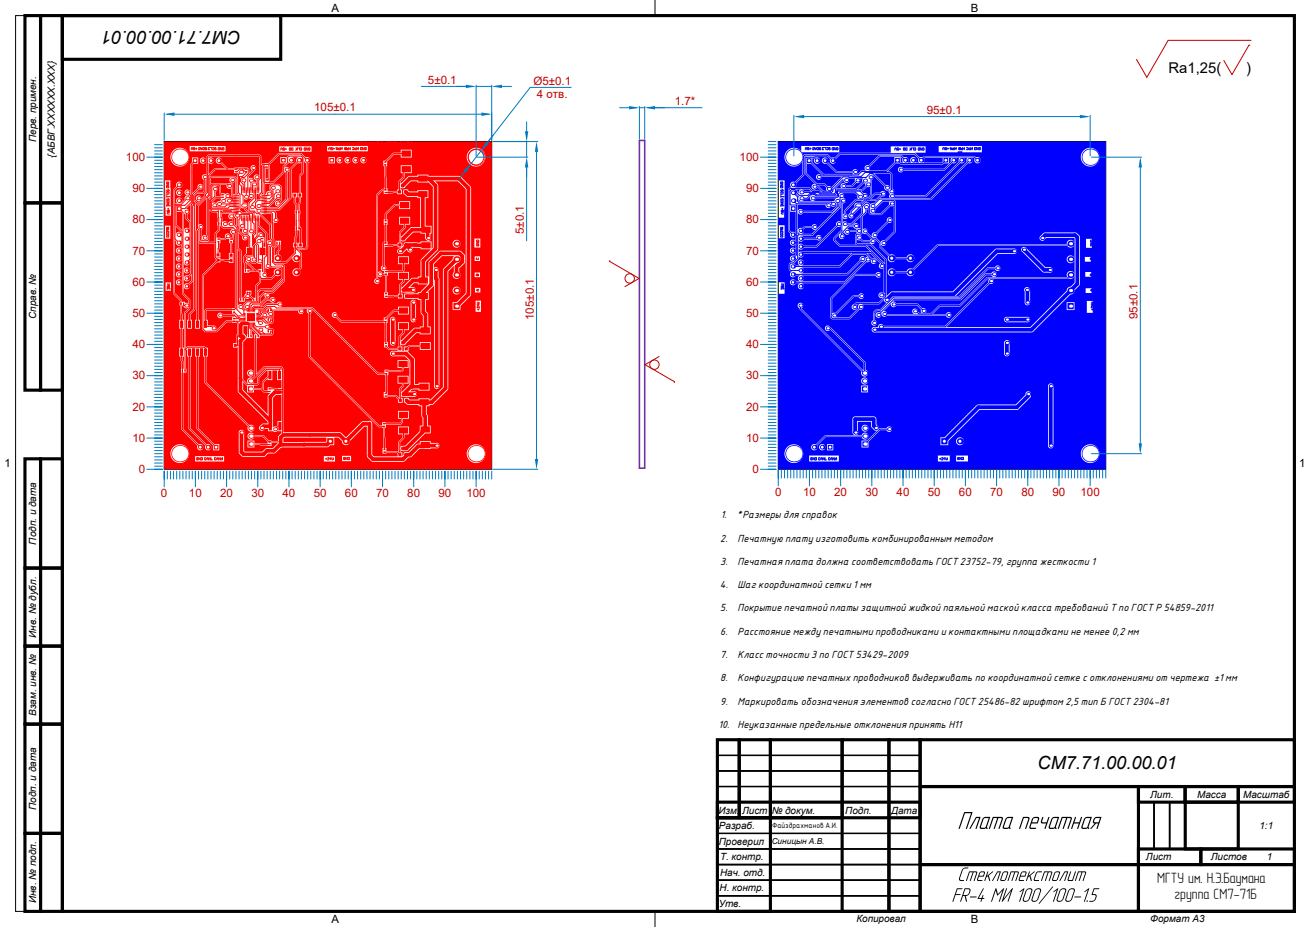
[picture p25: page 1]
Изм. Лист № докум. Разраб.; Подп.; Дата; Проверил Т. контр.; Н. контр. Утв.; Лит.; Масса; Масштаб; Лист; Листов; Синицын А.В.; Копировал; Формат А3; Нач. отд.; Файздрахманов А.И.; 4 отв.

{АБВГ.ХХХХХХ.ХХХ}

Перв. примен. Справ. № Подп. и дата Инв. № дубл. Взам. инв. № Подп. и дата Инв. № подл.

1. *Размеры для справок

2. Печатную плату изготовить комбинированным методом

3. Печатная плата должна соответствовать ГОСТ 23752-79, группа жесткости 1

4. Шаг координатной сетки 1 мм

5. Покрытие печатной платы защитной жидкой паяльной маской класса требований Т по ГОСТ Р 54859-2011

6. Расстояние между печатными проводниками и контактными площадками не менее 0,2 мм

7. Класс точности 3 по ГОСТ 53429-2009

8. Конфигурацию печатных проводников выдерживать по координатной сетке с отклонениями от чертежа ±1 мм

9. Маркировать обозначения элементов согласно ГОСТ 25486-82 шрифтом 2,5 тип Б ГОСТ 2304-81

10. Неуказанные предельные отклонения принять H11

МГТУ им. Н.Э.Баумана
группа СМ7-71Б

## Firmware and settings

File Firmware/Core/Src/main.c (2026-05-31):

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

/* Includes ------------------------------------------------------------------*/
#include "main.h"
#include "cmsis_os.h"

/* USER CODE BEGIN Includes */
#include "app.h"           // Пользовательская инициализация
#include "bsp/encoder.h"   // Драйвер энкодера (будет создан)
#include "bsp/drv8353.h"   // Драйвер DRV8353
#include "bsp/power_monitor.h"
#include "communication/can_protocol.h"
#include "communication/telemetry.h"
/* USER CODE END Includes */

/* USER CODE BEGIN PTD */
typedef struct {
    float position;
    float velocity;
    uint8_t enable;
} Command_t;
/* USER CODE END PTD */

ADC_HandleTypeDef hadc1;
CAN_HandleTypeDef hcan1;
I2C_HandleTypeDef hi2c1;
I2C_HandleTypeDef hi2c4;
SPI_HandleTypeDef hspi1;
TIM_HandleTypeDef htim1;
TIM_HandleTypeDef htim3;
UART_HandleTypeDef huart2;

/* FreeRTOS objects */
osThreadId_t defaultTaskHandle;
const osThreadAttr_t defaultTask_attributes = {
    .name = "defaultTask",
    .stack_size = 128 * 4,
    .priority = (osPriority_t) osPriorityNormal,
};

osThreadId_t EncoderTaskHandle;
const osThreadAttr_t EncoderTask_attributes = {
    .name = "EncoderTask",
    .stack_size = 512 * 4,
    .priority = (osPriority_t) osPriorityHigh,
};

osThreadId_t HallTaskHandle;
const osThreadAttr_t HallTask_attributes = {
    .name = "HallTask",
    .stack_size = 256 * 4,
    .priority = (osPriority_t) osPriorityHigh,
};

osThreadId_t ControlTaskHandle;
const osThreadAttr_t ControlTask_attributes = {
    .name = "ControlTask",
    .stack_size = 1024 * 4,
    .priority = (osPriority_t) osPriorityRealtime,
};

osThreadId_t CanTaskHandle;
const osThreadAttr_t CanTask_attributes = {
    .name = "CanTask",
    .stack_size = 512 * 4,
    .priority = (osPriority_t) osPriorityNormal,
};

osThreadId_t TelemetryTaskHandle;
const osThreadAttr_t TelemetryTask_attributes = {
    .name = "TelemetryTask",
    .stack_size = 512 * 4,
    .priority = (osPriority_t) osPriorityLow,
};

osThreadId_t DiagnosticsTaskHandle;
const osThreadAttr_t DiagnosticsTask_attributes = {
    .name = "DiagnosticsTask",
    .stack_size = 512 * 4,
    .priority = (osPriority_t) osPriorityLow,
};

// Очередь команд: 10 элементов по 12 байт (sizeof(Command_t))
osMessageQueueId_t CommandQueueHandle;
const osMessageQueueAttr_t CommandQueue_attributes = {
    .name = "CommandQueue"
};

osTimerId_t LedTimerHandle;
const osTimerAttr_t LedTimer_attributes = {
    .name = "LedTimer"
};

/* Function prototypes -------------------------------------------------------*/
void SystemClock_Config(void);
static void MX_GPIO_Init(void);
static void MX_ADC1_Init(void);
static void MX_CAN1_Init(void);
static void MX_I2C1_Init(void);
static void MX_I2C4_Init(void);
static void MX_TIM1_Init(void);
static void MX_USART2_UART_Init(void);
static void MX_SPI1_Init(void);
static void MX_TIM3_Init(void);
void StartDefaultTask(void *argument);
void StartEncoderTask(void *argument);
void StartHallTask(void *argument);
void StartControlTask(void *argument);
void StartCanTask(void *argument);
void StartTelemetryTask(void *argument);
void StartDiagnosticsTask(void *argument);
void LedTimerCallback(void *argument);

/* ===================== MAIN ===================== */
int main(void)
{
    HAL_Init();

    SystemClock_Config();   // <-- БУДЕТ ИСПРАВЛЕНА НИЖЕ

    MX_GPIO_Init();
    MX_ADC1_Init();      // <-- ИСПРАВЛЕНА
    MX_CAN1_Init();      // <-- ИСПРАВЛЕНА
    MX_I2C1_Init();
    MX_I2C4_Init();
    MX_TIM1_Init();      // <-- ИСПРАВЛЕНА (dead-time 250 нс)
    MX_USART2_UART_Init();
    MX_SPI1_Init();      // <-- ИСПРАВЛЕНА (Master, полный дуплекс)
    MX_TIM3_Init();      // <-- ИСПРАВЛЕНА (каналы 1,2,3)

    /* USER CODE BEGIN 2 */
    // Запуск ШИМ на всех 6 каналах TIM1
    HAL_TIM_PWM_Start(&htim1, TIM_CHANNEL_1);
    HAL_TIM_PWM_Start(&htim1, TIM_CHANNEL_2);
    HAL_TIM_PWM_Start(&htim1, TIM_CHANNEL_3);
    HAL_TIM_PWM_Start(&htim1, TIM_CHANNEL_1N);
    HAL_TIM_PWM_Start(&htim1, TIM_CHANNEL_2N);
    HAL_TIM_PWM_Start(&htim1, TIM_CHANNEL_3N);

    // Запуск таймера захвата для датчиков Холла (с прерываниями)
    HAL_TIM_IC_Start_IT(&htim3, TIM_CHANNEL_1);
    HAL_TIM_IC_Start_IT(&htim3, TIM_CHANNEL_2);
    HAL_TIM_IC_Start_IT(&htim3, TIM_CHANNEL_3);

    // Инициализация пользовательских модулей
    App_Init();
    /* USER CODE END 2 */

    osKernelInitialize();

    /* Создание таймера */
    LedTimerHandle = osTimerNew(LedTimerCallback, osTimerPeriodic, NULL, &LedTimer_attributes);
    osTimerStart(LedTimerHandle, pdMS_TO_TICKS(500));  // 500 мс

    /* Создание очереди (исправлено: размер элемента 12 байт) */
    CommandQueueHandle = osMessageQueueNew(10, sizeof(Command_t), &CommandQueue_attributes);

    /* Создание задач */
    defaultTaskHandle = osThreadNew(StartDefaultTask, NULL, &defaultTask_attributes);
    EncoderTaskHandle = osThreadNew(StartEncoderTask, NULL, &EncoderTask_attributes);
    HallTaskHandle = osThreadNew(StartHallTask, NULL, &HallTask_attributes);
    ControlTaskHandle = osThreadNew(StartControlTask, NULL, &ControlTask_attributes);
    CanTaskHandle = osThreadNew(StartCanTask, NULL, &CanTask_attributes);
    TelemetryTaskHandle = osThreadNew(StartTelemetryTask, NULL, &TelemetryTask_attributes);
    DiagnosticsTaskHandle = osThreadNew(StartDiagnosticsTask, NULL, &DiagnosticsTask_attributes);

    osKernelStart();

    while (1)
    {
        /* USER CODE END WHILE */
        /* USER CODE BEGIN 3 */
    }
    /* USER CODE END 3 */
}

/* ===================== Clock Configuration (ИСПРАВЛЕНА) ===================== */
void SystemClock_Config(void)
{
    RCC_OscInitTypeDef RCC_OscInitStruct = {0};
    RCC_ClkInitTypeDef RCC_ClkInitStruct = {0};

    // Настройка напряжения для 80 МГц
    if (HAL_PWREx_ControlVoltageScaling(PWR_REGULATOR_VOLTAGE_SCALE1) != HAL_OK)
        Error_Handler();

    // Используем HSE (внешний кварц 8 МГц)
    RCC_OscInitStruct.OscillatorType = RCC_OSCILLATORTYPE_HSE;
    RCC_OscInitStruct.HSEState = RCC_HSE_ON;
    RCC_OscInitStruct.PLL.PLLState = RCC_PLL_ON;
    RCC_OscInitStruct.PLL.PLLSource = RCC_PLLSOURCE_HSE;
    RCC_OscInitStruct.PLL.PLLM = 1;          // /1
    RCC_OscInitStruct.PLL.PLLN = 20;         // *20 => 160 МГц на VCO
    RCC_OscInitStruct.PLL.PLLP = RCC_PLLP_DIV7;   // не используется
    RCC_OscInitStruct.PLL.PLLQ = RCC_PLLQ_DIV2;   // не используется
    RCC_OscInitStruct.PLL.PLLR = RCC_PLLR_DIV2;   // /2 => 80 МГц SYSCLK

    if (HAL_RCC_OscConfig(&RCC_OscInitStruct) != HAL_OK)
        Error_Handler();

    RCC_ClkInitStruct.ClockType = RCC_CLOCKTYPE_HCLK | RCC_CLOCKTYPE_SYSCLK
                                  | RCC_CLOCKTYPE_PCLK1 | RCC_CLOCKTYPE_PCLK2;
    RCC_ClkInitStruct.SYSCLKSource = RCC_SYSCLKSOURCE_PLLCLK;
    RCC_ClkInitStruct.AHBCLKDivider = RCC_SYSCLK_DIV1;
    RCC_ClkInitStruct.APB1CLKDivider = RCC_HCLK_DIV1;
    RCC_ClkInitStruct.APB2CLKDivider = RCC_HCLK_DIV1;

    if (HAL_RCC_ClockConfig(&RCC_ClkInitStruct, FLASH_LATENCY_4) != HAL_OK)
        Error_Handler();
}

/* ===================== ADC1 (ИСПРАВЛЕНА: 2 канала, сканирование) ===================== */
static void MX_ADC1_Init(void)
{
    ADC_ChannelConfTypeDef sConfig = {0};

    hadc1.Instance = ADC1;
    hadc1.Init.ClockPrescaler = ADC_CLOCK_ASYNC_DIV1;
    hadc1.Init.Resolution = ADC_RESOLUTION_12B;
    hadc1.Init.DataAlign = ADC_DATAALIGN_RIGHT;
    hadc1.Init.ScanConvMode = ADC_SCAN_ENABLE;          // Включено сканирование
    hadc1.Init.EOCSelection = ADC_EOC_SEQ_CONV;         // Конец всей последовательности
    hadc1.Init.LowPowerAutoWait = DISABLE;
    hadc1.Init.ContinuousConvMode = DISABLE;
    hadc1.Init.NbrOfConversion = 2;                     // Два канала
    hadc1.Init.DiscontinuousConvMode = DISABLE;
    hadc1.Init.ExternalTrigConv = ADC_SOFTWARE_START;
    hadc1.Init.ExternalTrigConvEdge = ADC_EXTERNALTRIGCONVEDGE_NONE;
    hadc1.Init.DMAContinuousRequests = DISABLE;
    hadc1.Init.Overrun = ADC_OVR_DATA_PRESERVED;
    hadc1.Init.OversamplingMode = DISABLE;
    if (HAL_ADC_Init(&hadc1) != HAL_OK) Error_Handler();

    // Канал 5 (PB15) – ток фазы
    sConfig.Channel = ADC_CHANNEL_5;
    sConfig.Rank = 1;
    sConfig.SamplingTime = ADC_SAMPLETIME_47CYCLES_5;   // больше для фильтрации
    sConfig.SingleDiff = ADC_DIFFERENTIAL_ENDED;
    sConfig.OffsetNumber = ADC_OFFSET_NONE;
    sConfig.Offset = 0;
    if (HAL_ADC_ConfigChannel(&hadc1, &sConfig) != HAL_OK) Error_Handler();

    // Канал 6 (PA1) – напряжение шины
    sConfig.Channel = ADC_CHANNEL_6;
    sConfig.Rank = 2;
    if (HAL_ADC_ConfigChannel(&hadc1, &sConfig) != HAL_OK) Error_Handler();
}

/* ===================== CAN1 (ИСПРАВЛЕНА: 250 кбит/с, 80 МГц) ===================== */
static void MX_CAN1_Init(void)
{
    hcan1.Instance = CAN1;
    // Расчёт: частота таймера = 80 МГц / Prescaler.
    // Для 250 кбит/с: Prescaler = 20, BS1=13, BS2=2, тогда квантов = 1+13+2=16,
    // частота = 80e6 / (20 * 16) = 250 кГц.
    hcan1.Init.Prescaler = 20;
    hcan1.Init.Mode = CAN_MODE_NORMAL;
    hcan1.Init.SyncJumpWidth = CAN_SJW_1TQ;
    hcan1.Init.TimeSeg1 = CAN_BS1_13TQ;
    hcan1.Init.TimeSeg2 = CAN_BS2_2TQ;
    hcan1.Init.TimeTriggeredMode = DISABLE;
    hcan1.Init.AutoBusOff = DISABLE;
    hcan1.Init.AutoWakeUp = DISABLE;
    hcan1.Init.AutoRetransmission = ENABLE;
    hcan1.Init.ReceiveFifoLocked = DISABLE;
    hcan1.Init.TransmitFifoPriority = ENABLE;
    if (HAL_CAN_Init(&hcan1) != HAL_OK) Error_Handler();

    // Фильтр – пропускаем всё
    CAN_FilterTypeDef sFilterConfig = {0};
    sFilterConfig.FilterBank = 0;
    sFilterConfig.FilterMode = CAN_FILTERMODE_IDMASK;
    sFilterConfig.FilterScale = CAN_FILTERSCALE_32BIT;
    sFilterConfig.FilterIdHigh = 0;
    sFilterConfig.FilterIdLow = 0;
    sFilterConfig.FilterMaskIdHigh = 0;
    sFilterConfig.FilterMaskIdLow = 0;
    sFilterConfig.FilterFIFOAssignment = CAN_RX_FIFO0;
    sFilterConfig.FilterActivation = ENABLE;
    if (HAL_CAN_ConfigFilter(&hcan1, &sFilterConfig) != HAL_OK) Error_Handler();

    HAL_CAN_Start(&hcan1);
    HAL_CAN_ActivateNotification(&hcan1, CAN_IT_RX_FIFO0_MSG_PENDING);
}

/* ===================== SPI1 (ИСПРАВЛЕНА: Master, полный дуплекс, 16 бит) ===================== */
static void MX_SPI1_Init(void)
{
    hspi1.Instance = SPI1;
    hspi1.Init.Mode = SPI_MODE_MASTER;           // Master (было Slave)
    hspi1.Init.Direction = SPI_DIRECTION_2LINES; // Полный дуплекс
    hspi1.Init.DataSize = SPI_DATASIZE_16BIT;
    hspi1.Init.CLKPolarity = SPI_POLARITY_LOW;
    hspi1.Init.CLKPhase = SPI_PHASE_1EDGE;       // SPI Mode 0
    hspi1.Init.NSS = SPI_NSS_SOFT;               // Управление CS программно
    hspi1.Init.FirstBit = SPI_FIRSTBIT_MSB;
    hspi1.Init.TIMode = SPI_TIMODE_DISABLE;
    hspi1.Init.CRCCalculation = SPI_CRCCALCULATION_DISABLE;
    hspi1.Init.NSSPMode = SPI_NSS_PULSE_DISABLE;
    // Предделитель для частоты ~1-5 МГц (80 МГц / 16 = 5 МГц)
    if (HAL_SPI_Init(&hspi1) != HAL_OK) Error_Handler();
}

/* ===================== TIM1 (ИСПРАВЛЕНА: Dead Time = 250 нс) ===================== */
static void MX_TIM1_Init(void)
{
    TIM_MasterConfigTypeDef sMasterConfig = {0};
    TIM_OC_InitTypeDef sConfigOC = {0};
    TIM_BreakDeadTimeConfigTypeDef sBreakDeadTimeConfig = {0};

    htim1.Instance = TIM1;
    htim1.Init.Prescaler = 0;
    htim1.Init.CounterMode = TIM_COUNTERMODE_CENTERALIGNED1; // Центрированный
    htim1.Init.Period = 3999;    // 4000-1, 20 кГц при 80 МГц
    htim1.Init.ClockDivision = TIM_CLOCKDIVISION_DIV1;
    htim1.Init.RepetitionCounter = 0;
    htim1.Init.AutoReloadPreload = TIM_AUTORELOAD_PRELOAD_ENABLE;
    if (HAL_TIM_PWM_Init(&htim1) != HAL_OK) Error_Handler();

    sMasterConfig.MasterOutputTrigger = TIM_TRGO_RESET;
    sMasterConfig.MasterOutputTrigger2 = TIM_TRGO2_RESET;
    sMasterConfig.MasterSlaveMode = TIM_MASTERSLAVEMODE_DISABLE;
    if (HAL_TIMEx_MasterConfigSynchronization(&htim1, &sMasterConfig) != HAL_OK) Error_Handler();

    sConfigOC.OCMode = TIM_OCMODE_PWM1;
    sConfigOC.Pulse = 0;   // начальная скважность 0
    sConfigOC.OCPolarity = TIM_OCPOLARITY_HIGH;
    sConfigOC.OCNPolarity = TIM_OCNPOLARITY_HIGH;
    sConfigOC.OCFastMode = TIM_OCFAST_DISABLE;
    sConfigOC.OCIdleState = TIM_OCIDLESTATE_RESET;
    sConfigOC.OCNIdleState = TIM_OCNIDLESTATE_RESET;

    for (int ch = TIM_CHANNEL_1; ch <= TIM_CHANNEL_3; ch++)
        if (HAL_TIM_PWM_ConfigChannel(&htim1, &sConfigOC, ch) != HAL_OK) Error_Handler();

    // Настройка Dead Time (250 нс)
    sBreakDeadTimeConfig.OffStateRunMode = TIM_OSSR_ENABLE;
    sBreakDeadTimeConfig.OffStateIDLEMode = TIM_OSSI_ENABLE;
    sBreakDeadTimeConfig.LockLevel = TIM_LOCKLEVEL_OFF;
    // DeadTime рассчитывается: tDTS = 1/80e6 = 12.5 нс, DT = 20 * 12.5 = 250 нс
    sBreakDeadTimeConfig.DeadTime = 20;
    sBreakDeadTimeConfig.BreakState = TIM_BREAK_DISABLE;
    sBreakDeadTimeConfig.BreakPolarity = TIM_BREAKPOLARITY_HIGH;
    sBreakDeadTimeConfig.BreakFilter = 0;
    sBreakDeadTimeConfig.Break2State = TIM_BREAK2_DISABLE;
    sBreakDeadTimeConfig.AutomaticOutput = TIM_AUTOMATICOUTPUT_ENABLE;
    if (HAL_TIMEx_ConfigBreakDeadTime(&htim1, &sBreakDeadTimeConfig) != HAL_OK) Error_Handler();

    HAL_TIM_MspPostInit(&htim1);
}

/* ===================== TIM3 (ИСПРАВЛЕНА: каналы 1,2,3) ===================== */
static void MX_TIM3_Init(void)
{
    TIM_MasterConfigTypeDef sMasterConfig = {0};
    TIM_IC_InitTypeDef sConfigIC = {0};

    htim3.Instance = TIM3;
    htim3.Init.Prescaler = 0;
    htim3.Init.CounterMode = TIM_COUNTERMODE_UP;
    htim3.Init.Period = 65535;
    htim3.Init.ClockDivision = TIM_CLOCKDIVISION_DIV1;
    htim3.Init.AutoReloadPreload = TIM_AUTORELOAD_PRELOAD_DISABLE;
    if (HAL_TIM_IC_Init(&htim3) != HAL_OK) Error_Handler();

    sMasterConfig.MasterOutputTrigger = TIM_TRGO_RESET;
    sMasterConfig.MasterSlaveMode = TIM_MASTERSLAVEMODE_DISABLE;
    if (HAL_TIMEx_MasterConfigSynchronization(&htim3, &sMasterConfig) != HAL_OK) Error_Handler();

    sConfigIC.ICPolarity = TIM_INPUTCHANNELPOLARITY_RISING;
    sConfigIC.ICSelection = TIM_ICSELECTION_DIRECTTI;
    sConfigIC.ICPrescaler = TIM_ICPSC_DIV1;
    sConfigIC.ICFilter = 0;

    if (HAL_TIM_IC_ConfigChannel(&htim3, &sConfigIC, TIM_CHANNEL_1) != HAL_OK) Error_Handler();
    if (HAL_TIM_IC_ConfigChannel(&htim3, &sConfigIC, TIM_CHANNEL_2) != HAL_OK) Error_Handler();
    if (HAL_TIM_IC_ConfigChannel(&htim3, &sConfigIC, TIM_CHANNEL_3) != HAL_OK) Error_Handler();
}

/* ===================== Остальные функции (без изменений) ===================== */
static void MX_USART2_UART_Init(void) { /* ... как было ... */ }
static void MX_I2C1_Init(void) { /* ... */ }
static void MX_I2C4_Init(void) { /* ... */ }
static void MX_GPIO_Init(void) { /* ... как было, но добавьте CS энкодера если нужно */ }

/* ===================== Пример задачи ControlTask (заглушка) ===================== */
void StartControlTask(void *argument)
{
    /* USER CODE BEGIN StartControlTask */
    for(;;)
    {
        // Основной цикл управления
        osDelay(10);
    }
    /* USER CODE END StartControlTask */
}

/* Остальные задачи (StartEncoderTask, StartHallTask и т.д.) – аналогично, пока пустые */
void StartDefaultTask(void *argument) { for(;;) osDelay(1); }
void StartEncoderTask(void *argument) { for(;;) osDelay(10); }
void StartHallTask(void *argument) { for(;;) osDelay(1); }
void StartCanTask(void *argument) { for(;;) osDelay(5); }
void StartTelemetryTask(void *argument) { for(;;) osDelay(100); }
void StartDiagnosticsTask(void *argument) { for(;;) osDelay(500); }

void LedTimerCallback(void *argument)
{
    HAL_GPIO_TogglePin(LED_DEBUG_1_GPIO_Port, LED_DEBUG_1_Pin);
}

void Error_Handler(void)
{
    __disable_irq();
    while (1) { }
}

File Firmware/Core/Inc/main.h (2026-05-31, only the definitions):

#define INA219_I2C_ADDR         0x40    // типовой адрес (A0=A1=GND)
#define ENC_CS_PIN              GPIO_PIN_6      // PB6
#define ENC_CS_PORT             GPIOB
#define ENC_SCK_PIN             GPIO_PIN_5      // PA5 (SPI1_SCK)
#define ENC_SCK_PORT            GPIOA
#define ENC_MISO_PIN            GPIO_PIN_11     // PA11 (SSI_MISO)
#define ENC_MISO_PORT           GPIOA
#define DRV_EN_PIN              GPIO_PIN_8      
#define DRV_EN_PORT             GPIOB
#define DRV_nFAULT_PIN          GPIO_PIN_9      
#define DRV_nFAULT_PORT         GPIOB
#define DRV_nSLEEP_PIN          GPIO_PIN_10     // PB10
#define DRV_nSLEEP_PORT         GPIOB
#define CAN_ID_TARGET_ANGLE     0x100   // приём: целевой угол (2 байта, градусы * 10)
#define CAN_ID_TELEMETRY        0x101   // передача: текущий угол, статус
#define PWM_PERIOD              3999    // 4000-1, частота 20 кГц при SYSCLK=80 МГц
#define LED_DEBUG_1_Pin         GPIO_PIN_13
#define LED_DEBUG_1_GPIO_Port   GPIOC
#define LED_DEBUG_2_Pin         GPIO_PIN_14
#define LED_DEBUG_2_GPIO_Port   GPIOC
#define HALL_A_Pin              GPIO_PIN_6
#define HALL_A_GPIO_Port        GPIOA
#define HALL_B_Pin              GPIO_PIN_7
#define HALL_B_GPIO_Port        GPIOA
#define HALL_C_Pin              GPIO_PIN_0
#define HALL_C_GPIO_Port        GPIOB

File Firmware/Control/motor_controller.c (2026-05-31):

#include "control/motor_controller.h"

#include "control/pid.h"

#include "bsp/encoder.h"
#include "bsp/drv8353.h"

#include <math.h>

static MotorController_t motor;

static PID_t position_pid;
static PID_t velocity_pid;

static float NormalizeDuty(float value)
{
    if(value > 1.0f)
        value = 1.0f;

    if(value < -1.0f)
        value = -1.0f;

    return value;
}

void MotorController_Init(void)
{
    motor.enabled = false;

    motor.target_position_deg = 0.0f;

    PID_Init(
            &position_pid,
            0.15f,
            0.0f,
            0.005f,
            -100.0f,
             100.0f);

    PID_Init(
            &velocity_pid,
            0.02f,
            0.001f,
            0.0f,
            -1.0f,
             1.0f);
}

void MotorController_Enable(void)
{
    motor.enabled = true;

    DRV8353_Enable();
}

void MotorController_Disable(void)
{
    motor.enabled = false;

    DRV8353_Disable();

    PID_Reset(&position_pid);
    PID_Reset(&velocity_pid);
}

void MotorController_SetPosition(
        float position_deg)
{
    motor.target_position_deg =
            position_deg;
}

void MotorController_Update(
        float dt)
{
    if(!motor.enabled)
        return;

    Encoder_Update();

    motor.current_position_deg =
            Encoder_GetAngleDeg();

    motor.current_velocity_deg_s =
            Encoder_GetVelocity() *
            57.2957795f;

    motor.target_velocity_deg_s =
            PID_Update(
                &position_pid,
                motor.target_position_deg,
                motor.current_position_deg,
                dt);

    motor.control_output =
            PID_Update(
                &velocity_pid,
                motor.target_velocity_deg_s,
                motor.current_velocity_deg_s,
                dt);

    float duty =
            NormalizeDuty(
                motor.control_output);

    float dutyA =
            0.5f +
            0.5f * duty;

    float dutyB =
            0.5f -
            0.5f * duty;

    float dutyC =
            0.5f;

    DRV8353_SetDutyABC(
            dutyA,
            dutyB,
            dutyC);
}

MotorController_t*
MotorController_GetHandle(void)
{
    return &motor;
}

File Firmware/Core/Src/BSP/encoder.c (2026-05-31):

#include "bsp/encoder.h"

#include <math.h>

extern SPI_HandleTypeDef hspi1;

static Encoder_t encoder;

/* ------------------------------------
 * Локальные функции
 * ------------------------------------ */

static uint32_t Encoder_GetTimestampMs(void)
{
    return HAL_GetTick();
}

/* ------------------------------------
 * Инициализация
 * ------------------------------------ */

HAL_StatusTypeDef Encoder_Init(void)
{
    encoder.raw_position = 0;
    encoder.raw_prev = 0;

    encoder.mechanical_angle_deg = 0.0f;
    encoder.mechanical_angle_rad = 0.0f;
    encoder.velocity_rad_s = 0.0f;

    encoder.timestamp_prev = Encoder_GetTimestampMs();
    encoder.initialized = true;

    return HAL_OK;
}

/* ------------------------------------
 * Чтение SSI
 * ------------------------------------ */

HAL_StatusTypeDef Encoder_ReadRaw(uint16_t *position)
{
    HAL_StatusTypeDef status;

    uint16_t tx_word = 0x0000;
    uint16_t rx_word = 0x0000;

    status = HAL_SPI_TransmitReceive(
                &hspi1,
                (uint8_t*)&tx_word,
                (uint8_t*)&rx_word,
                1,
                10);

    if(status != HAL_OK)
    {
        return status;
    }

    rx_word &= 0x0FFF;

    *position = rx_word;

    return HAL_OK;
}

/* ------------------------------------
 * Обновление данных
 * ------------------------------------ */

HAL_StatusTypeDef Encoder_Update(void)
{
    uint16_t raw;

    HAL_StatusTypeDef status;

    status = Encoder_ReadRaw(&raw);

    if(status != HAL_OK)
    {
        return status;
    }

    uint32_t now = Encoder_GetTimestampMs();

    float dt =
        ((float)(now - encoder.timestamp_prev)) / 1000.0f;

    int32_t delta =
        (int32_t)raw -
        (int32_t)encoder.raw_prev;

    if(delta > 2048)
    {
        delta -= 4096;
    }

    if(delta < -2048)
    {
        delta += 4096;
    }

    if(dt > 0.0f)
    {
        encoder.velocity_rad_s =
            ((float)delta) *
            (2.0f * (float)M_PI / 4096.0f) /
            dt;
    }

    encoder.raw_prev = raw;
    encoder.timestamp_prev = now;

    encoder.raw_position = raw;

    encoder.mechanical_angle_deg =
        raw * ENCODER_MECH_ANGLE_SCALE;

    encoder.mechanical_angle_rad =
        encoder.mechanical_angle_deg *
        ((float)M_PI / 180.0f);

    return HAL_OK;
}

/* ------------------------------------
 * Getters
 * ------------------------------------ */

uint16_t Encoder_GetRaw(void)
{
    return encoder.raw_position;
}

float Encoder_GetAngleDeg(void)
{
    return encoder.mechanical_angle_deg;
}

float Encoder_GetAngleRad(void)
{
    return encoder.mechanical_angle_rad;
}

float Encoder_GetVelocity(void)
{
    return encoder.velocity_rad_s;
}

Encoder_t* Encoder_GetHandle(void)
{
    return &encoder;
}
